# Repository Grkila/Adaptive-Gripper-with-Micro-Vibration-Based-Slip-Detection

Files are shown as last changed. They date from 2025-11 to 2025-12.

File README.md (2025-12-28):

# Adaptive Gripper with Micro-Vibration Based Slip Detection

A complete mechatronics project featuring a parallel gripper with real-time slip detection using a 3D magnetic sensor (TLV493D) and FFT-based signal analysis. The system autonomously adjusts grip force by detecting incipient slip through micro-vibration analysis, preventing object loss while minimizing applied force.

**Author:** Dušan Grković  
**Mentor:** Prof. Dr. Zoran Jeličić  
**Institution:** Faculty of Technical Sciences, Novi Sad  
**Date:** 2025

> All components of this project (PCB layout, firmware, and desktop application) were developed by the author. The mechanical design is based on [1] with significant modifications for sensor integration.

<p align="center">
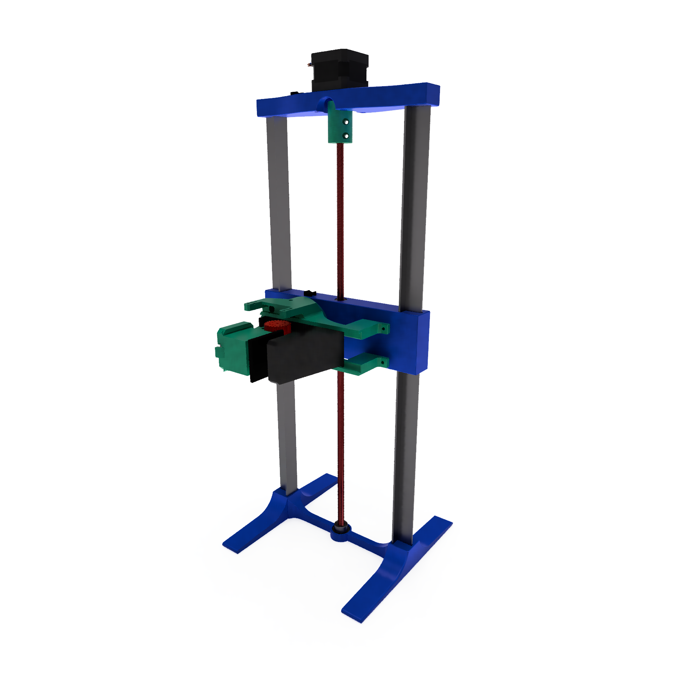
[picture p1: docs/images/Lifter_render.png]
  
</p>

<!-- ADD THIS BLOCK HERE -->
<p align="center">
  <a href="https://www.youtube.com/watch?v=gOe6JvAW2Xo">
    
  </a>
</p>
<!-- END BLOCK -->

## Table of Contents

1. [Overview](#overview)
2. [System Architecture](#system-architecture)
3. [Hardware](#hardware)
   - [Mechanical Design](#mechanical-design)
   - [Sensor Element](#sensor-element)
   - [Automated Test Platform](#automated-test-platform)
   - [Electronics](#electronics)
4. [Firmware](#firmware)
   - [Architecture](#firmware-architecture)
   - [Signal Processing](#signal-processing)
   - [State Machine](#state-machine)
5. [Communication Protocol](#communication-protocol)
6. [Desktop Application](#desktop-application)
7. [Test Results](#test-results)
8. [Hardware Files](#hardware-files)
9. [Repository Structure](#repository-structure)
10. [Build Instructions](#build-instructions)
11. [References](#references)

## Overview

This project presents a novel approach to adaptive grip force control where the conventional strain gauge based system is replaced with a contactless 3D magnetic sensor. The system detects the onset of slippage (incipient slip) by analyzing micro-vibrations generated during the stick-slip phenomenon.

### Key Features

- Real-time slip detection using FFT spectral analysis (40 Hz to 120 Hz band)
- Contactless measurement using TLV493D 3D Hall effect sensor
- Custom elastic sensor element with optimized natural frequency (~180 Hz)
- Dual-core FreeRTOS implementation on ESP32 (2 kHz sampling rate)
- Automated test platform with sensorless homing using TMC2209
- Desktop application for signal visualization and parameter tuning

### Operating Principle

1. **Stick-Slip Effect:** When an object begins to slip, the contact surface undergoes cycles of sticking and releasing, generating characteristic high-frequency vibrations
2. **Mechanical Transduction:** A custom elastic mechanism (planar spiral flexure) converts surface micro-displacements into magnet movement
3. **Magnetic Sensing:** The TLV493D sensor measures the magnet position changes caused by vibrations
4. **Spectral Analysis:** Real-time FFT identifies the spectral signature of slippage
5. **Adaptive Control:** A finite state machine increases grip force proportionally to slip intensity

## System Architecture

<p align="center">
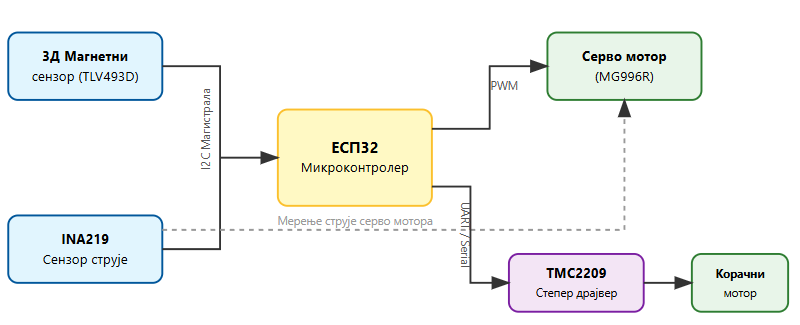
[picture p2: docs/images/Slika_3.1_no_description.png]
  
</p>

The system consists of three main subsystems:

| Subsystem | Components | Function |
|---|---|---|
| Sensing | TLV493D magnetic sensor, INA219 current sensor | Measure deformation and motor current |
| Control | ESP32 microcontroller, FreeRTOS | Real-time signal processing and decision making |
| Actuation | MG996R servo motor, NEMA17 stepper | Gripper actuation and test platform movement |

## Hardware

### Mechanical Design

The parallel gripper uses a rack and pinion mechanism for linear motion transformation. One finger is active (moving) while the other is passive (stationary) with the integrated sensor element.

**Note:** The mechanical design of the gripper is based on the open-source "Robot-manipulator" project by AnnaW21 [1], with significant modifications to integrate the custom sensor element and optimize it for the specific requirements of this project.

<p align="center">
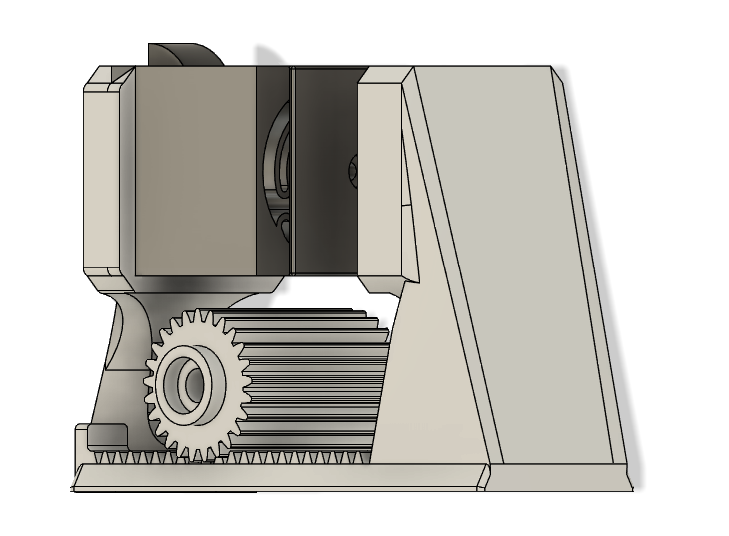
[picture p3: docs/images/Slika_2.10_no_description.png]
  
</p>

**Key specifications:**

- Material: PETG (FDM 3D printed)
- Actuator: MG996R servo motor (11 kg·cm torque at 6V)
- Drive: Rack and pinion with metal gears
- Contact surface: TPU insert for increased friction coefficient

CAD files are available in the `hardware/gripper/` directory as STEP format.

### Sensor Element

The elastic sensor element is the core innovation of this project. It uses a planar spiral flexure geometry that acts as a 3-DOF spring with the magnet mounted at the center.

<p align="center">
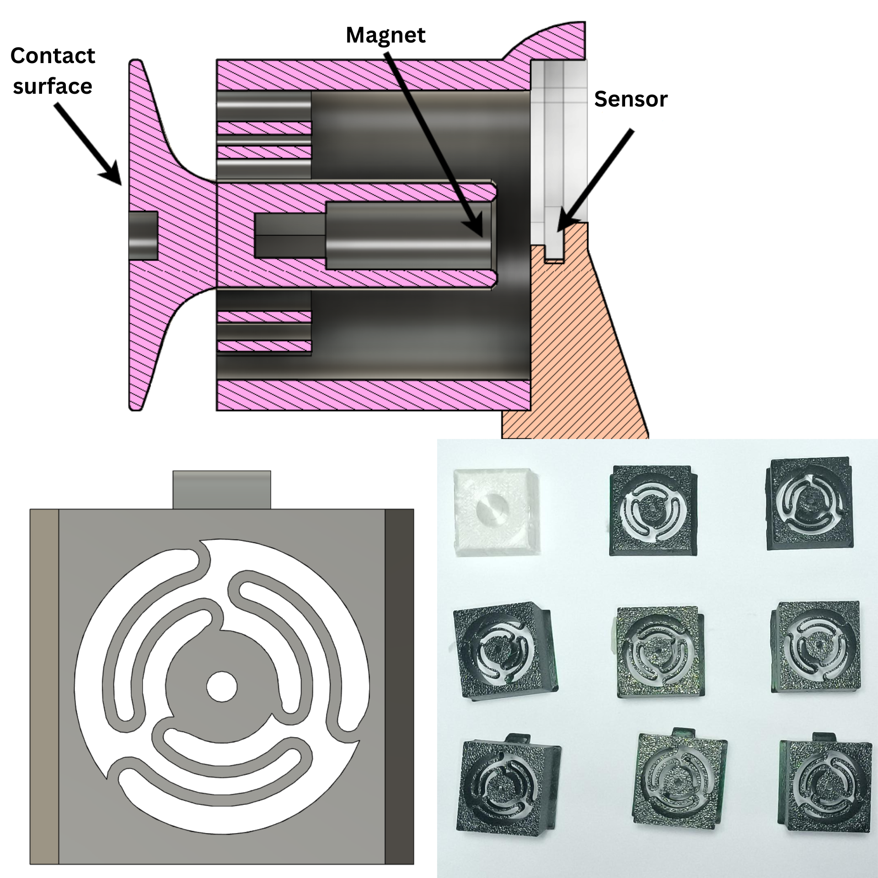
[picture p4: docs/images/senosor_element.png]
  
</p>

**Design parameters:**

- Geometry: 3-arm symmetric planar spiral flexure
- Natural frequency: ~180 Hz (tuned above slip detection band)
- Air gap: 4 mm between magnet and sensor
- Lever amplification: Geometry amplifies small displacements at contact surface

The natural frequency was empirically tuned through 10+ iterations using impulse response testing.

### Automated Test Platform

To ensure repeatable experimental conditions and eliminate operator subjectivity, a dedicated vertical positioning system was designed and built.

<p align="center">
  
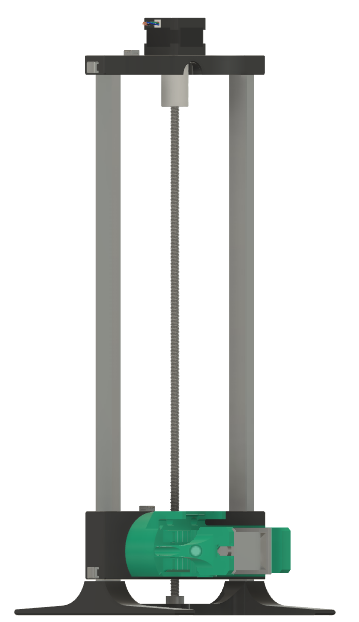
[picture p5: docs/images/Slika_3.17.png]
  
</p>

**Purpose:** Manual lifting introduces inconsistent accelerations and mechanical vibrations that can mask the slip signal or cause false detections. This platform guarantees identical velocity profiles across all test cycles. The use of this platform eliminates human variability in lifting speed and stability, which is essential for validating the sensitivity of the slip detection algorithm.

**Construction:**

- Frame: Aluminum T extrusion 
- Drive: M8x1.25mm lead screw coupled to NEMA17 stepper motor
- Controller: TMC2209 driver with StallGuard4 for sensorless homing
- Resolution: 2560 steps/mm (16 microsteps, 1.8 degree motor)

**Sensorless Homing Algorithm:**

Instead of physical limit switches, the system uses the TMC2209's StallGuard feature to detect when the platform reaches the mechanical stop:

1. Reduce motor current to 500mA (prevents damage on collision)
2. Move upward briefly (ensures room for acceleration)
3. Move downward while polling SG_RESULT via UART
4. When load increases (SG_RESULT drops below threshold for 3 consecutive reads), stop and set position to zero
5. Restore nominal current and acceleration parameters

> **Note:** The videos below are sped up for demonstration purposes.

<p align="center">
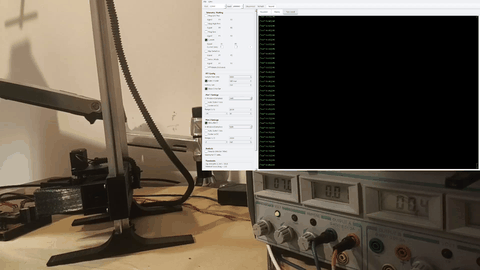
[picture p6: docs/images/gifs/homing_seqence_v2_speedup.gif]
  
  <br>
  <a href="docs/powerpoint/Video/homing_seqence_v2_speedup.mp4">▶️ Watch original video</a>
</p>

CAD files available in: `hardware/lifting platform/lifter.step`

### Electronics

<p align="center">
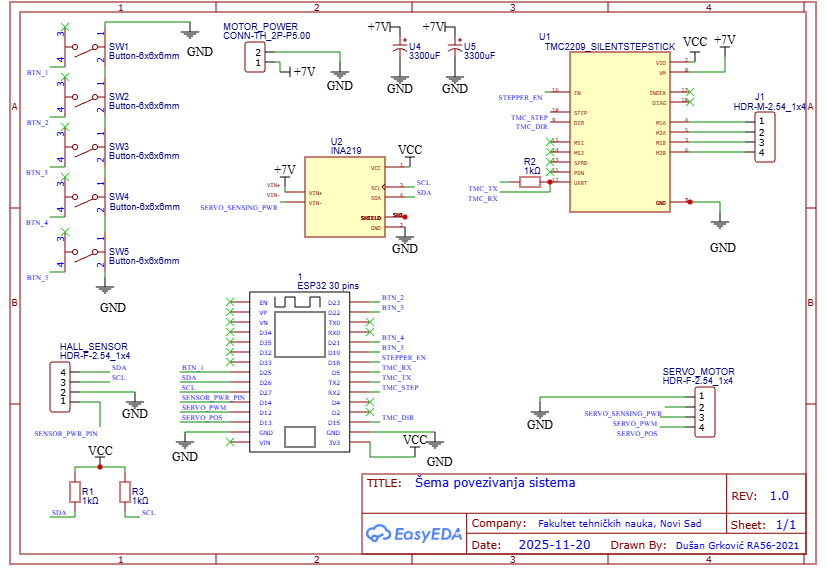
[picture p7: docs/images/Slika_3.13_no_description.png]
  
</p>

The electronic system is built around an ESP32 development module with the following interfaces:

| Component | Interface | Function |
|---|---|---|
| TLV493D | I2C (1 MHz) | 3D magnetic field measurement |
| INA219 | I2C | Servo motor current sensing |
| MG996R | PWM (50 Hz) | Gripper actuation |
| TMC2209 | UART + Step/Dir | Stepper motor control with StallGuard |
| Buttons (x5) | GPIO | Manual control interface |

**Button Functions:**

Five tactile buttons (active low with internal pull-up resistors) provide manual control:

| Button | Function |
|---|---|
| SW1 | Start adaptive gripping (grasp with optimal force) |
| SW2 | Full gripper open |
| SW3 | Raise platform to predefined height |
| SW4 | Lower platform to home position |
| SW5 | Emergency stop (halt platform at current position) |

**Power supply:** Single 7V input with bulk capacitors (2x 3300μF) for motor transient filtering.

Complete schematic available at: `hardware/pcb/Schematic_Gripper_diplomski.pdf`

PCB design files (EasyEDA format) available in: `hardware/pcb/EasyEda/`

## Firmware

### Firmware Architecture

The firmware implements a deterministic control loop using FreeRTOS on ESP32's dual-core architecture.

<p align="center">
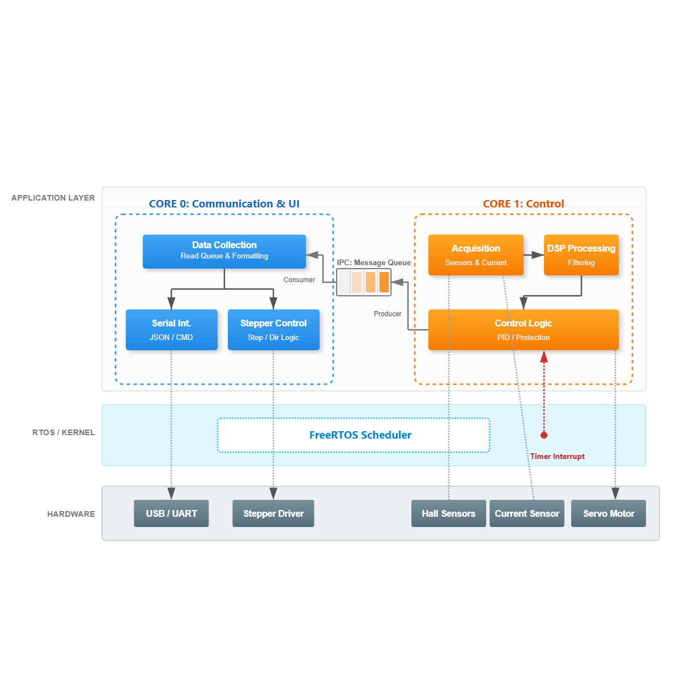
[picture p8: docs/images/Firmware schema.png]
  
</p>

**Core assignment:**

- **Core 0:** Communication task (telemetry, debug interface)
- **Core 1:** Real-time control loop (sensor acquisition, DSP, state machine)

Inter-core data sharing is protected by mutex to prevent race conditions.

### Scan Cycle

The main loop follows a PLC-style scan cycle triggered by hardware timer at 2 kHz:

1. **Read Inputs:** Magnetic sensor (2 kHz), current sensor (100 Hz), buttons (20 Hz)
2. **Process Logic:** Digital filtering, FFT computation, slip detection, FSM update
3. **Write Outputs:** Servo PWM update if position changed

### Signal Processing

<p align="center">
  
</p>

The signal processing pipeline:

1. **Calibration:** Offset removal based on startup readings
2. **Low-pass Filter (500 Hz):** Sensor noise elimination
3. **Band-split Filter (30 Hz):** Separates DC (grip force) from AC (vibrations)
4. **High-pass Filter:** AC component extraction by subtraction
5. **FFT Analysis:** 128-sample window, spectral power computation

**Slip indicator calculation:**

```
slip_indicator = frequency_weighted_power(40 Hz to 120 Hz band)
```

The frequency weighting gives higher importance to higher frequency components characteristic of slip events.

### State Machine

<p align="center">
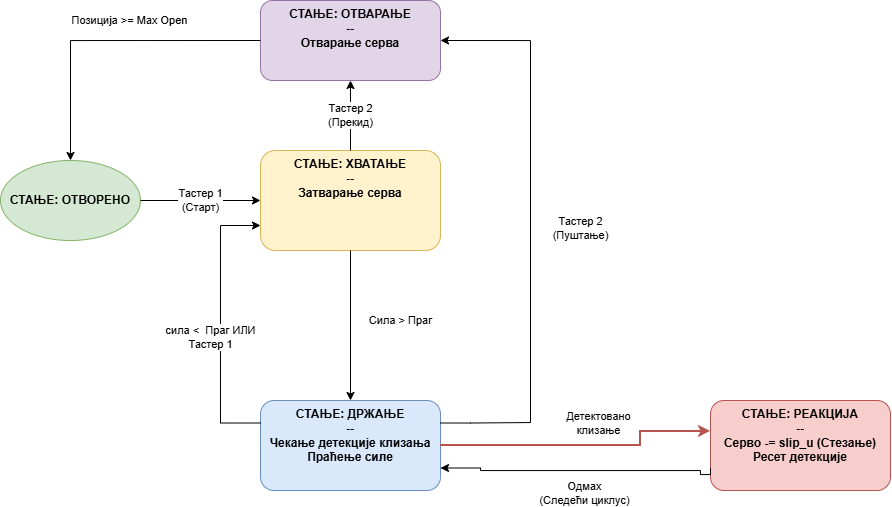
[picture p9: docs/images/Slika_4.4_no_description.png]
  
</p>

The gripper control FSM has five states:

| State | Entry Condition | Behavior |
|---|---|---|
| OPEN | Default / Button 2 | Gripper fully open |
| OPENING | Release command | Gradual opening |
| GRASPING | Button 1 | Close until contact detected (magnitude > threshold) |
| HOLDING | Contact established | Monitor for slip, maintain position |
| REACTING | Slip detected | Increase grip force proportionally |

## Communication Protocol

The firmware implements a bidirectional JSON-based protocol over serial (2000000 baud) for telemetry and configuration.

### Telemetry Output

Standard telemetry packet (fields depend on enabled streams):

```json
{"mlx":0.30,"mly":-0.46,"mlz":-0.28,"mag":0.71,"slip":0,"s_ind":1.76}
```

Each packet ends with a pipe character and XOR checksum for validation: `|5A`

### Configuration Commands

Send JSON commands to toggle specific data streams:

| Command | Description |
|---|---|
| `{"fft": true/false}` | Exclusive FFT streaming mode (pauses other metrics) |
| `{"mag_lowpass": true/false}` | Low-pass filtered magnetic data (mlx, mly, mlz, mag) |
| `{"mag_highpass": true/false}` | High-pass filtered magnetic data (mhx, mhy, mhz) |
| `{"mag_raw": true/false}` | Raw magnetic sensor data (rmx, rmy, rmz) |
| `{"current": true/false}` | Current sensor reading (cur) |
| `{"slip": true/false}` | Slip detection status and indicator (slip, s_ind) |
| `{"servo": true/false}` | Servo position and grip mode (srv, grp) |
| `{"system": true/false}` | System timing diagnostics (t) |

### FFT Data Format

When FFT mode is enabled, spectral data is streamed as:

```json
{"type":"fft","data":[10.5, 2.3, 0.1, ...]}
```

The data array contains 64 magnitude values from the high-pass filtered signal.

Full protocol documentation: `firmware/Thesis_Gripper/debugCommands.md`

## Desktop Application

A Python-based desktop application was developed for real-time signal visualization and system tuning.

### Features

- Activation/deactivation of telemetry streams (reduces serial bus load)
- Serial port and baud rate selection
- Configurable Y-axis range with auto-scaling option
- Configurable X-axis window (samples)
- Automatic DC centering
- Data recording to file
- Playback of recorded data with adjustable speed
- XOR checksum validation
- Multiple plots in single window
- Signal appearance customization (color, thickness, line type)
- Export to standard formats (CSV, PNG, matplotlib, SVG)
- Threshold indicators for parameter tuning
- Real-time FFT view with spectrogram history

### Screenshots

**Real-time signal visualization:**

<p align="center">
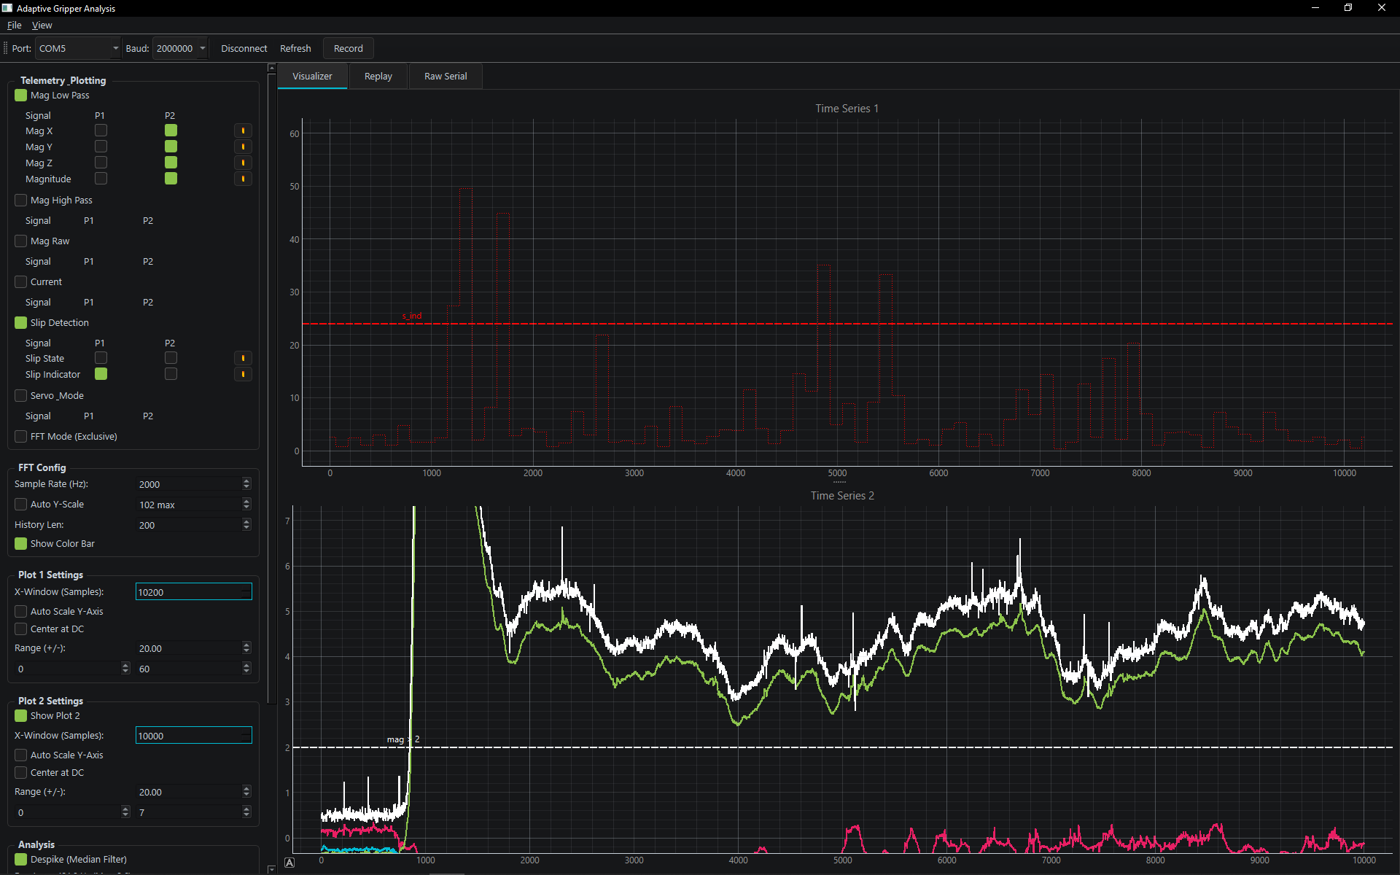
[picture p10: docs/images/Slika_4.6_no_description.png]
  
</p>

**Raw serial terminal:**

<p align="center">
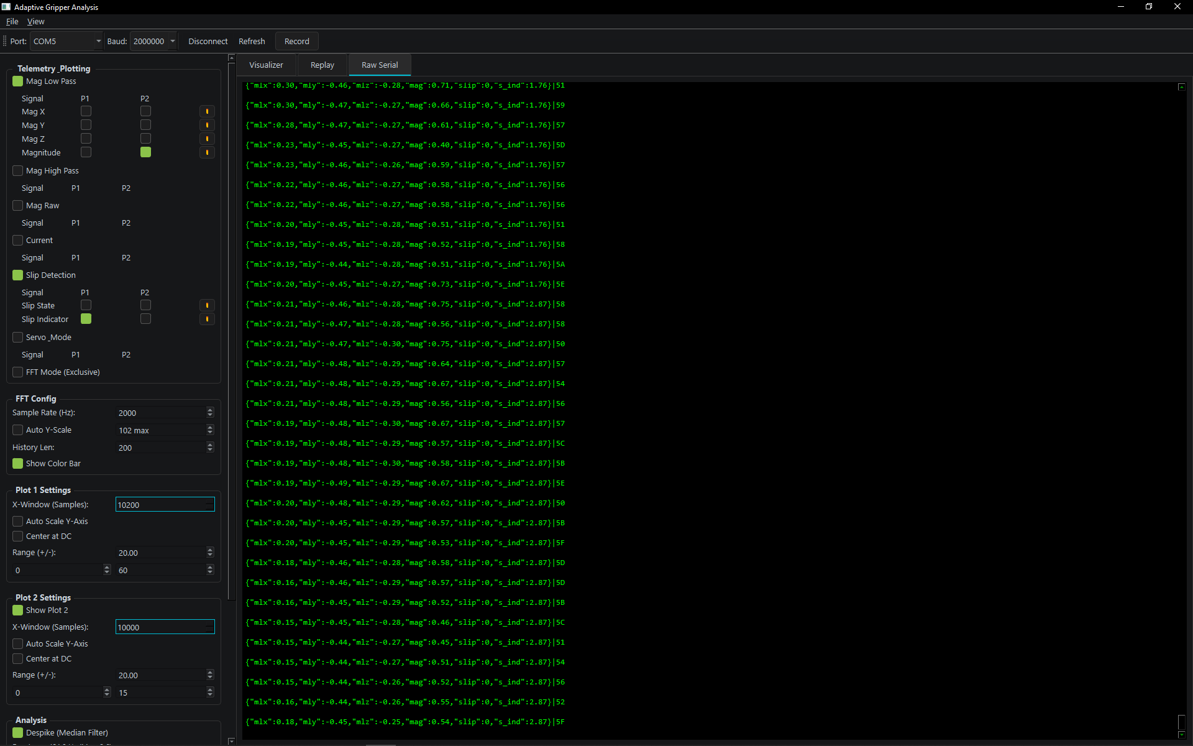
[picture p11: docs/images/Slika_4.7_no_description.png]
  
</p>

**Recorded data replay:**

<p align="center">
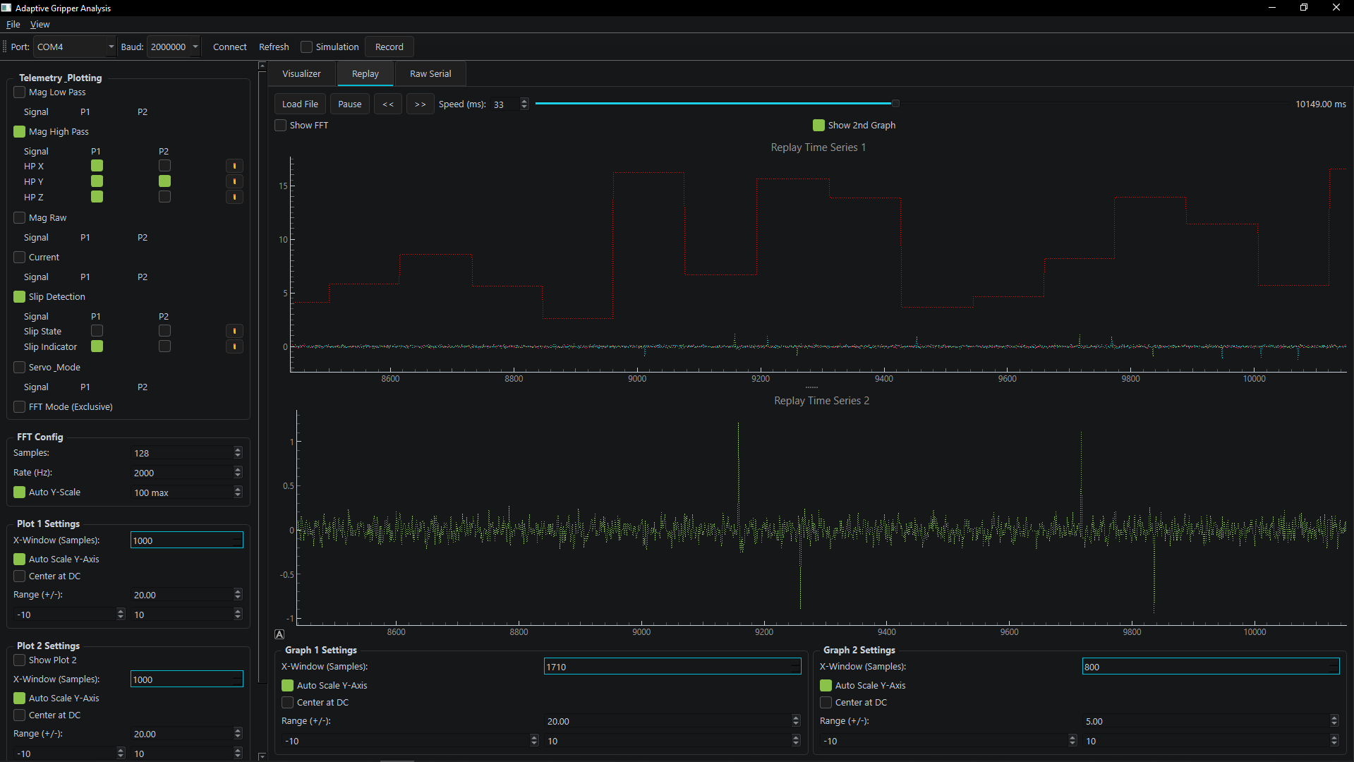
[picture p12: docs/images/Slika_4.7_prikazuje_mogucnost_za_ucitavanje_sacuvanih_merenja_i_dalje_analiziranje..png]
  
</p>

**FFT analysis with spectrogram:**

<p align="center">
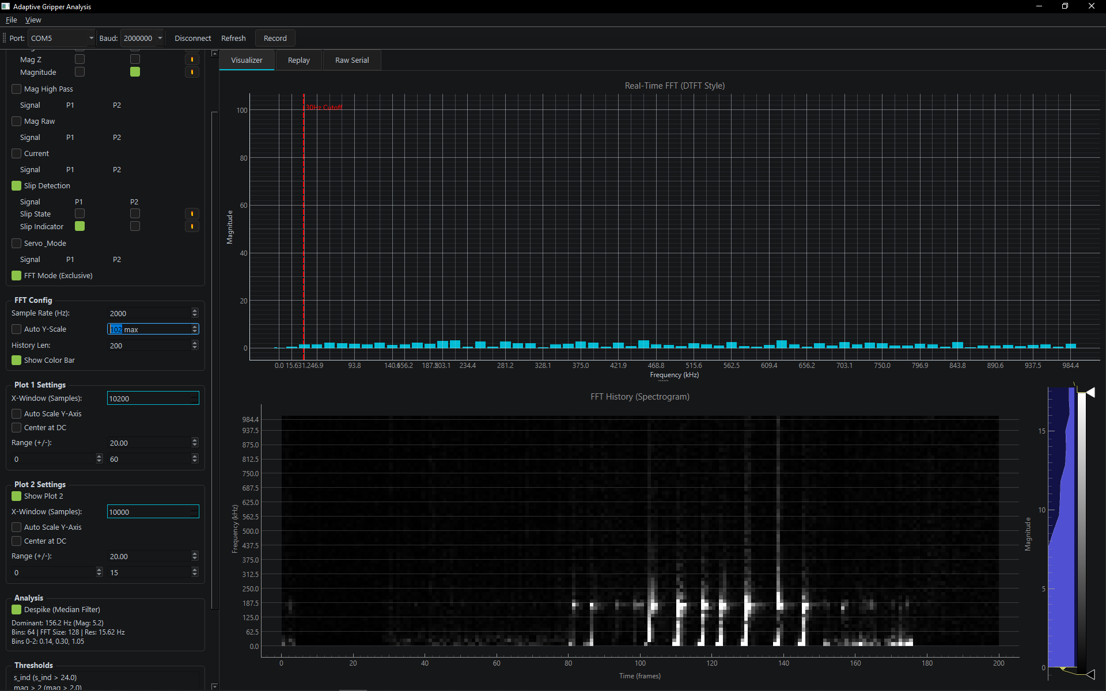
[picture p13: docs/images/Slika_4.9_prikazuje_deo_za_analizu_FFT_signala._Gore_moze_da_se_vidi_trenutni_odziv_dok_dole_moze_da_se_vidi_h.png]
  
</p>

## Test Results

The system was validated on various objects to demonstrate robustness and adaptability.

### Soft Objects (Sponge)

The gripper successfully grasped and held a deformable sponge with minimal compression (~5%), demonstrating the algorithm's ability to apply just enough force.

<p align="center">
  
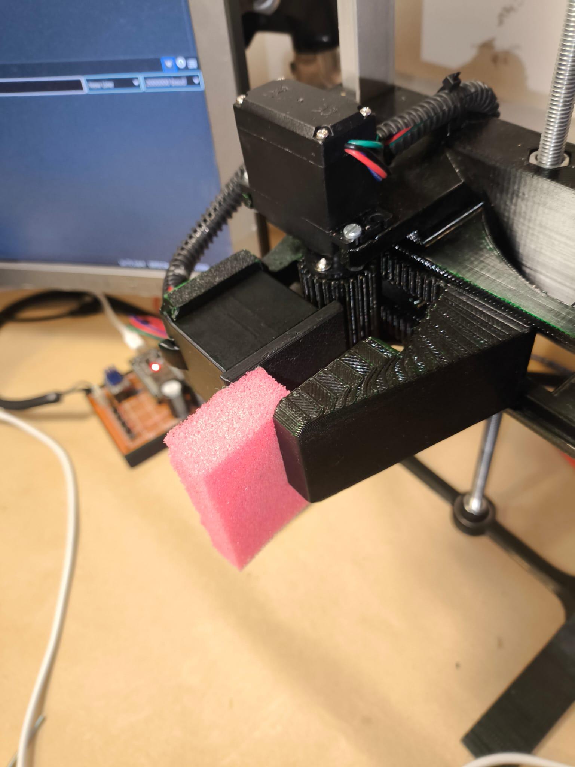
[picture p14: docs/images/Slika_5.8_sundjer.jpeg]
  
</p>

<p align="center">
  
  <br>
  <a href="docs/powerpoint/Video/sponge_speedup.mp4">▶️ Watch original video</a>
</p>

### Soft Objects (Cardboard Box)

A thin cardboard box (155g) was held without visible wall deformation, confirming optimal force application.

<p align="center">
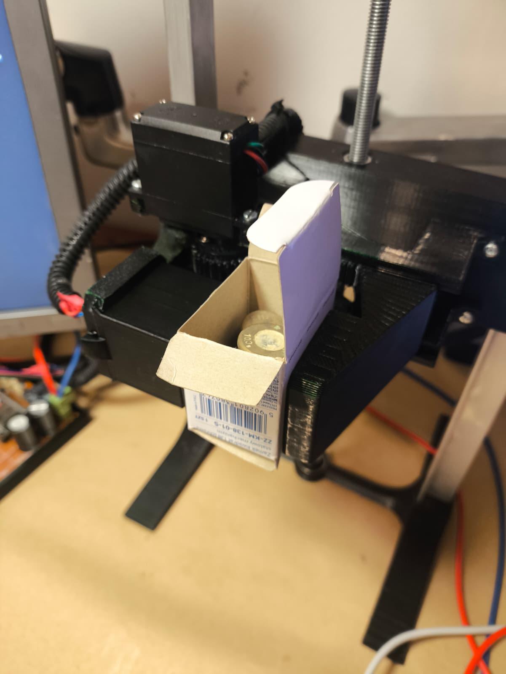
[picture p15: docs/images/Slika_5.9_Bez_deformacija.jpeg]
  
</p>

### Soft Objects (Cardboard Box)
A thin rigid PETG box (20g) was held without slippage, later it was added weights up to 500g confirming optimal force application.
Minimal slip ~5mm.

<p align="center">
  
  <br>
  <a href="docs/powerpoint/Video/testbox_speedup.mp4">▶️ Watch original video</a>
</p>

### Irregular Geometry (Cylindrical Object)

A 220g cylindrical tool was successfully held despite line contact instead of surface contact. Initial slip of ~10mm occurred during lifting transition before the system stabilized.

<p align="center">
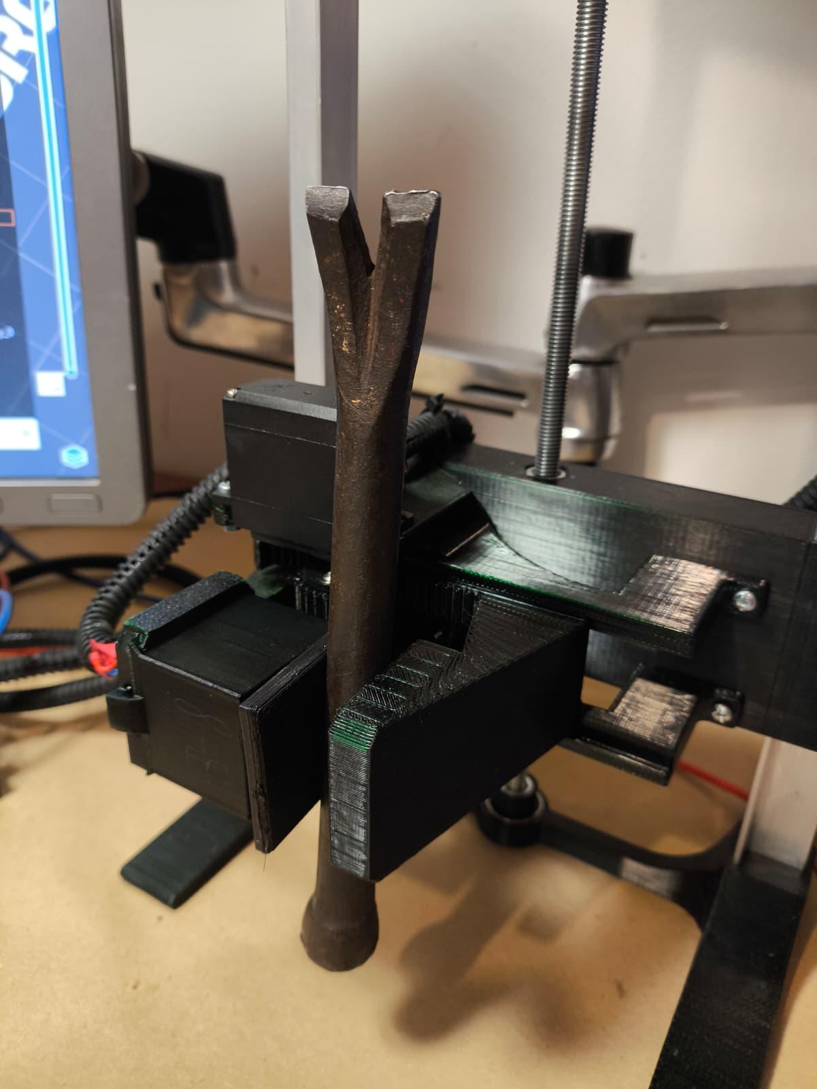
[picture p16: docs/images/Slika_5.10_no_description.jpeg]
  
</p>

<p align="center">
  
  <br>
  <a href="docs/powerpoint/Video/cylinder_speedup.mp4">▶️ Watch original video</a>
</p>

### Fragile Objects (Balloon)

The system also demonstrates capability with fragile objects like air-filled and water-filled balloons, adjusting grip force to prevent bursting while maintaining a secure hold.

<p align="center">
  
  
  <br>
  <a href="docs/powerpoint/Video/ballone_speedup.mp4">▶️ Watch air balloon video</a> | 
  <a href="docs/powerpoint/Video/waterballone_speedup.mp4">▶️ Watch water balloon video</a>
</p>

### Performance Metrics

| Parameter | Value |
|---|---|
| Sampling frequency | 2000 Hz |
| FFT window | 128 samples (64 ms) |
| Minimum reaction time | ~90 ms (buffer fill + processing + motor response) |
| Slip detection band | 40 Hz to 120 Hz |
| Slip threshold | 30 (weighted spectral power) |
| Contact detection threshold | 2.0 mT (magnitude change) |

## Hardware Files

All mechanical and electronic design files are provided for replication:

### Mechanical (STEP format)

| File | Description |
|---|---|
| `hardware/gripper/gripper.step` | Complete gripper assembly including rack and pinion mechanism, sensor housing, and finger geometry |
| `hardware/lifting platform/lifter.step` | Vertical test platform with linear guides and lead screw mount |

### Electronics

| File | Description |
|---|---|
| `hardware/pcb/Schematic_Gripper_diplomski.pdf` | Full circuit schematic (printable) |
| `hardware/pcb/EasyEda/1-Schematic_Gripper_diplomski.json` | EasyEDA schematic source file |
| `hardware/pcb/EasyEda/1-PCB_PCB_Gripper_diplomski.json` | EasyEDA PCB layout source file |

The PCB was designed but not manufactured; the prototype uses perfboard construction.

## Repository Structure

```
Adaptive-Gripper-with-Micro-Vibration-Based-Slip-Detection/
├── firmware/
│   └── Thesis_Gripper/
│       ├── Thesis_Gripper.ino    # Main program
│       ├── debugCommands.md               # Serial protocol documentation
│       └── src/
│           ├── Config.h                    # System configuration
│           ├── Types.h                     # Data structures
│           ├── Globals.h/.cpp              # Shared variables
│           ├── Drivers/                    # Hardware abstraction
│           │   ├── MagneticSensor.*        # TLV493D driver
│           │   ├── CurrentSensor.*         # INA219 driver
│           │   ├── ServoDriver.*           # PWM servo control
│           │   ├── MotorDriver.*           # TMC2209 stepper control
│           │   └── Buttons.*               # Button input handling
│           └── Logic/                      # Algorithms
│               ├── Filters.*               # Digital filters
│               ├── FFTProcessor.*          # FFT computation
│               ├── SlipDetection.*         # Slip detection algorithm
│               ├── GrippingFSM.*           # State machine
│               └── DebugTask.*             # Telemetry system
├── hardware/
│   ├── gripper/
│   │   └── gripper.step                    # Gripper CAD model
│   ├── lifting platform/
│   │   └── lifter.step                     # Test platform CAD model
│   └── pcb/
│       ├── Schematic_Gripper_diplomski.pdf # Circuit schematic
│       └── EasyEda/                        # PCB design files
├── software/
│   ├── signal_analysis_gui.py              # Desktop application
│   └── requirements.txt                    # Python dependencies
├── docs/
│   ├── images/                             # Documentation images
│   └── DIPLOMSKI.pdf                # Full thesis document
└── data/                                   # Sample measurement data
```

## Build Instructions

### Firmware

**Requirements:**

- Arduino IDE 2.x or PlatformIO
- ESP32 board support package
- Libraries: Wire, WiFi, arduinoFFT, TMCStepper, FastAccelStepper

**Steps:**

1. Open `firmware/Thesis_Gripper/Thesis_Gripper.ino` in Arduino IDE
2. Select board: ESP32 Dev Module
3. Configure upload speed: 921600
4. Adjust pin definitions in `Config.h` if needed
5. Upload to ESP32

### Desktop Application

**Requirements:**

- Python 3.8+
- Dependencies listed in `software/requirements.txt`

**Steps:**

```bash
cd software
pip install -r requirements.txt
python signal_analysis_gui.py
```

### Hardware

**3D Printing:**

- Material: PETG recommended (PLA may deform under friction heat)
- Layer height: 0.2 mm
- Infill: 20% for structural parts, gyroid infill
- Nozzle : 0.4 mm for sensor, 0.6 mm for rest of assembly 
- Wall loops 4 for sensor, 2 for rest of assembly
- Print orientation: Follow original STEP file orientation for optimal strength

**Electronics:**

- Prototype built on perfboard (PCB files provided but not manufactured)
- I2C pull-up resistors: 1kΩ (high speed operation)
- TMC2209 connection: 1kΩ resistor in series with UART TX

## References

1. AnnaW21. "Robot-manipulator." GitHub, 2021. [Online]. Available: https://github.com/AnnaW21/Robot-manipulator. (Repository containing 3D models and code for a robotic manipulator, whose gripper mechanical design was adapted for this work).

Full thesis with detailed derivations: `docs/DIPLOMSKI.pdf`

Presentation slides: [Diplomski_prez.pptx](docs/powerpoint/Diplomski_prez.pptx) (Requires PowerPoint 2018 or newer)

## License

This project was developed as a diploma thesis. For licensing inquiries, contact the author.

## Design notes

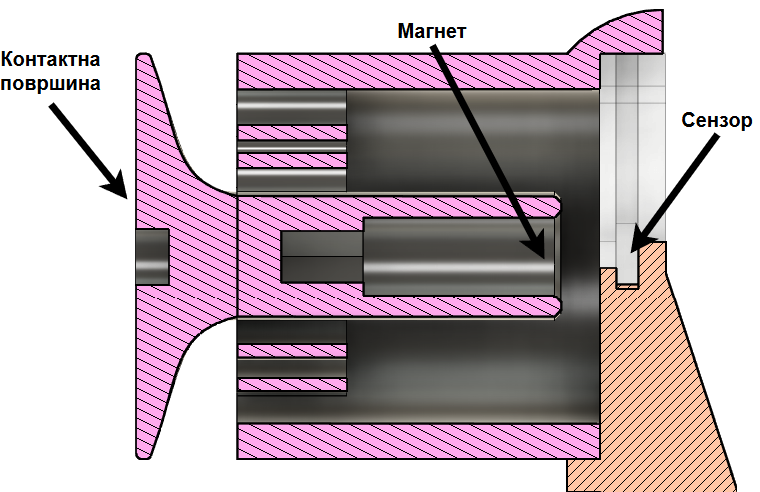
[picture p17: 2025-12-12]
docs/images/Slika_2.7_Primenom_ovog_resenja_je_osigurano_povecanje_amplituda,_ali_ovo_povecanje_dolazi_sa_cenom,_a_to_je_v.png

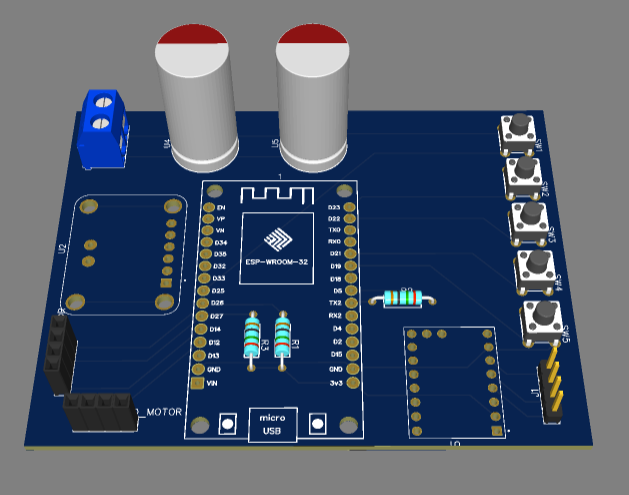
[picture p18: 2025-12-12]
docs/images/Slika_3.14_no_description.png

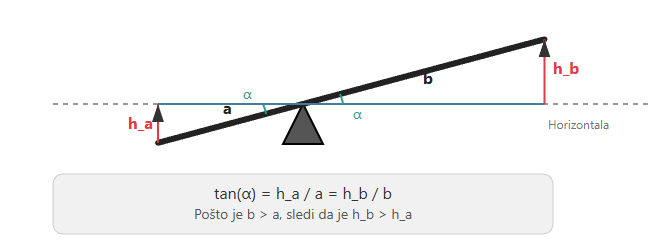
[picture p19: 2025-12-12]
docs/images/Slika_2.6_Za_levu_stranu_poluge,_visina_je_,_a_horizontalna_duzina_je_,_kao_sto_se_vidi_na_slici_2.6.png

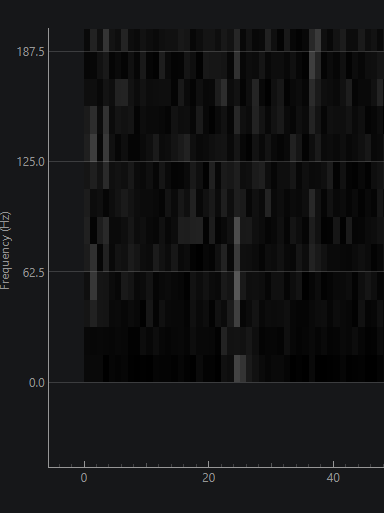
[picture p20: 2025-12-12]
docs/images/Slika_5.4_Kao_sto_se_vidi_na_slici_5.4_pre_klizanja_mozemo_da_uocimo_sum,_tokom_klizanja_se_vidi_visi_intentzi.png

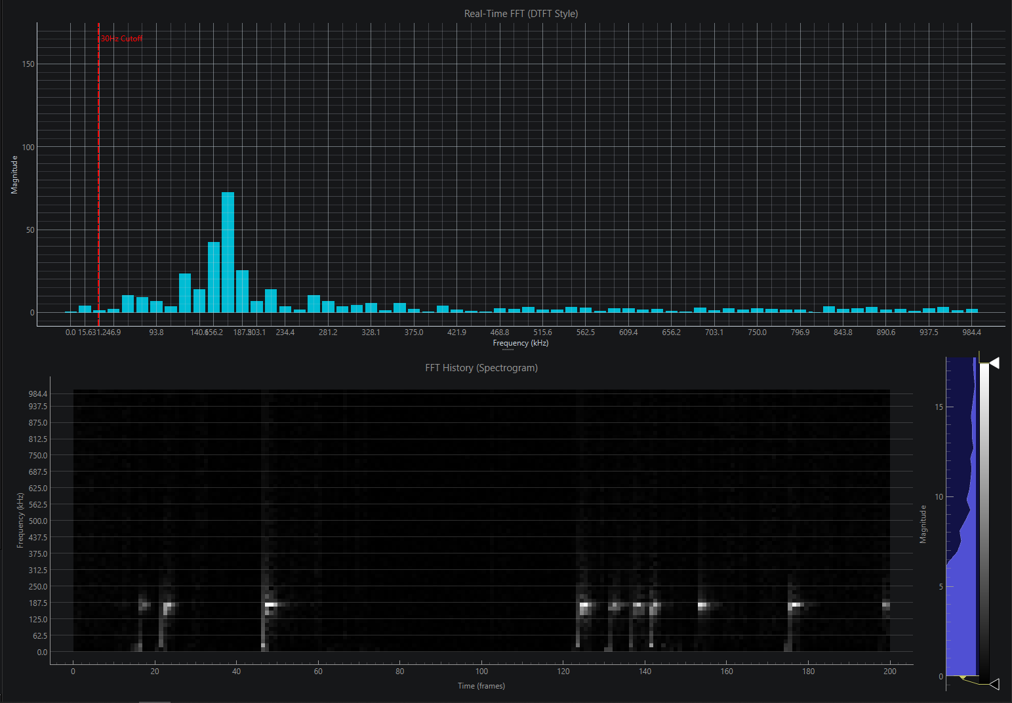
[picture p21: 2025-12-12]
docs/images/Slika_3.5_no_description.png

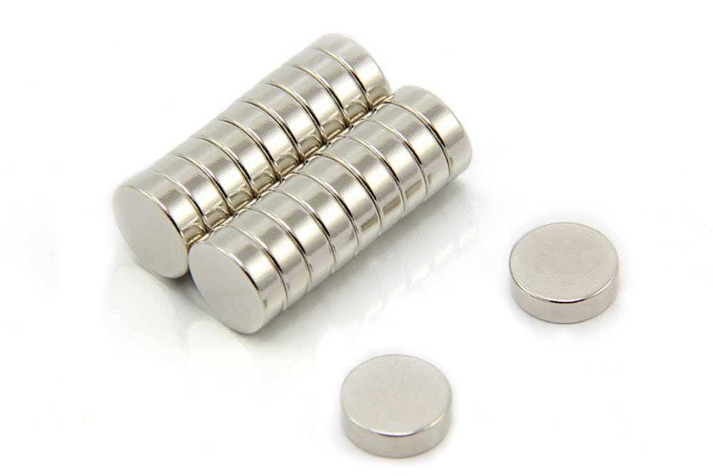
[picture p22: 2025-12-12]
docs/images/Slika_3.8_no_description.png

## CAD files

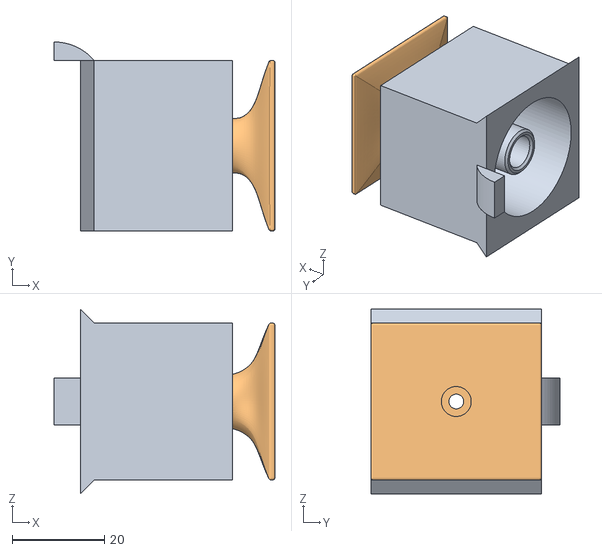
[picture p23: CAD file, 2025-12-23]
docs/powerpoint/3D model/coushon_compliant_v3_0.4mm nozzle.obj
47.9 x 41.0 x 40.0

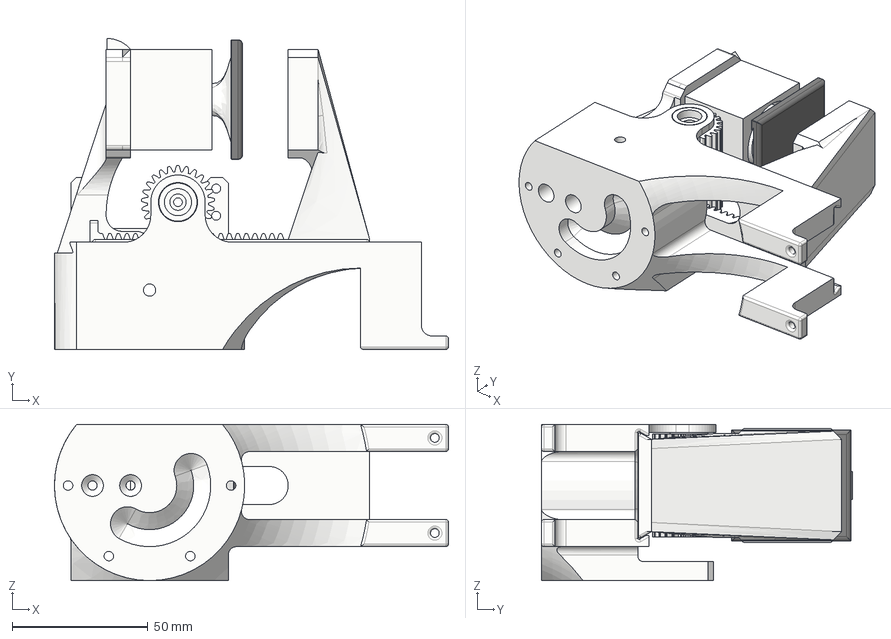
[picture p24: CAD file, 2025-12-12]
hardware/gripper/gripper.step
145.0 x 114.5 x 57.5 mm
губка_стационарная
sensor holder
coushon_compliant_v3_0.4mm nozzle
cushon cover

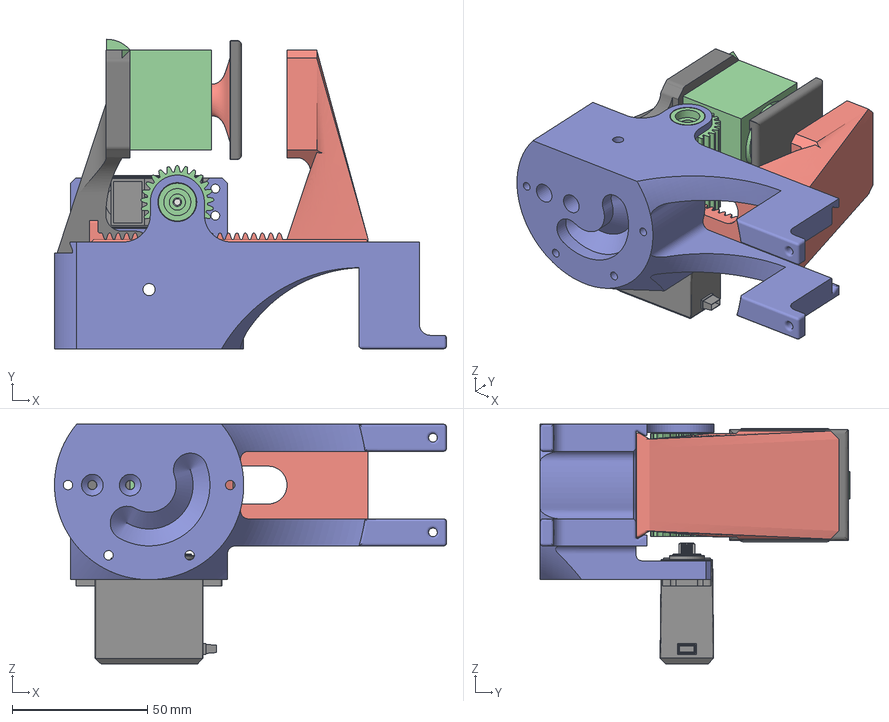
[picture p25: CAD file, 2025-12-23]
docs/powerpoint/3D model/gripper.3mf
145.0 x 114.5 x 88.6 mm

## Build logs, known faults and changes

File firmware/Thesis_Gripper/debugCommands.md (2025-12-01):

# Debug System Commands

**Baud Rate:** 921600  
**Format:** JSON  
**Terminator:** Newline (`\n`)

## Configuration Commands

Send these JSON strings to the Serial port to toggle specific data streams.

### FFT Mode (Exclusive)
*   `{"fft": true}` - Enables exclusive FFT streaming mode. (Pauses other metrics)
*   `{"fft": false}` - Disables FFT mode and returns to normal telemetry.

### Telemetry Toggles
*   `{"mag_lowpass": true}` / `false` - Low-Pass Filtered Magnetic Data (`mlx`, `mly`, `mlz`, `mag`). Alias: `mag_filtered`
*   `{"mag_highpass": true}` / `false` - High-Pass Filtered Magnetic Data (`mhx`, `mhy`, `mhz`)
*   `{"mag_raw": true}` / `false` - Raw Magnetic Data (`rmx`, `rmy`, `rmz`)
*   `{"current": true}` / `false` - Current Sensor (`cur`)
*   `{"slip": true}` / `false` - Slip Detection (`slip`, `s_ind`)
*   `{"servo": true}` / `false` - Servo & Mode (`srv`, `grp`)
*   `{"system": true}` / `false` - System Timing (`t`)

## Output Formats

### Normal Telemetry
Returns a JSON object with enabled fields:
```json
{"mx":12.3,"my":45.6,"mz":78.9,"mag":90.1,"cur":10.5,"slip":0,"t":500}
```

### FFT Data
Streamed when FFT mode is enabled:
```json
{"type":"fft","data":[10.5, 2.3, 0.1, ...]}
```
*   **data**: Array of magnitude values (High-Pass Filtered)

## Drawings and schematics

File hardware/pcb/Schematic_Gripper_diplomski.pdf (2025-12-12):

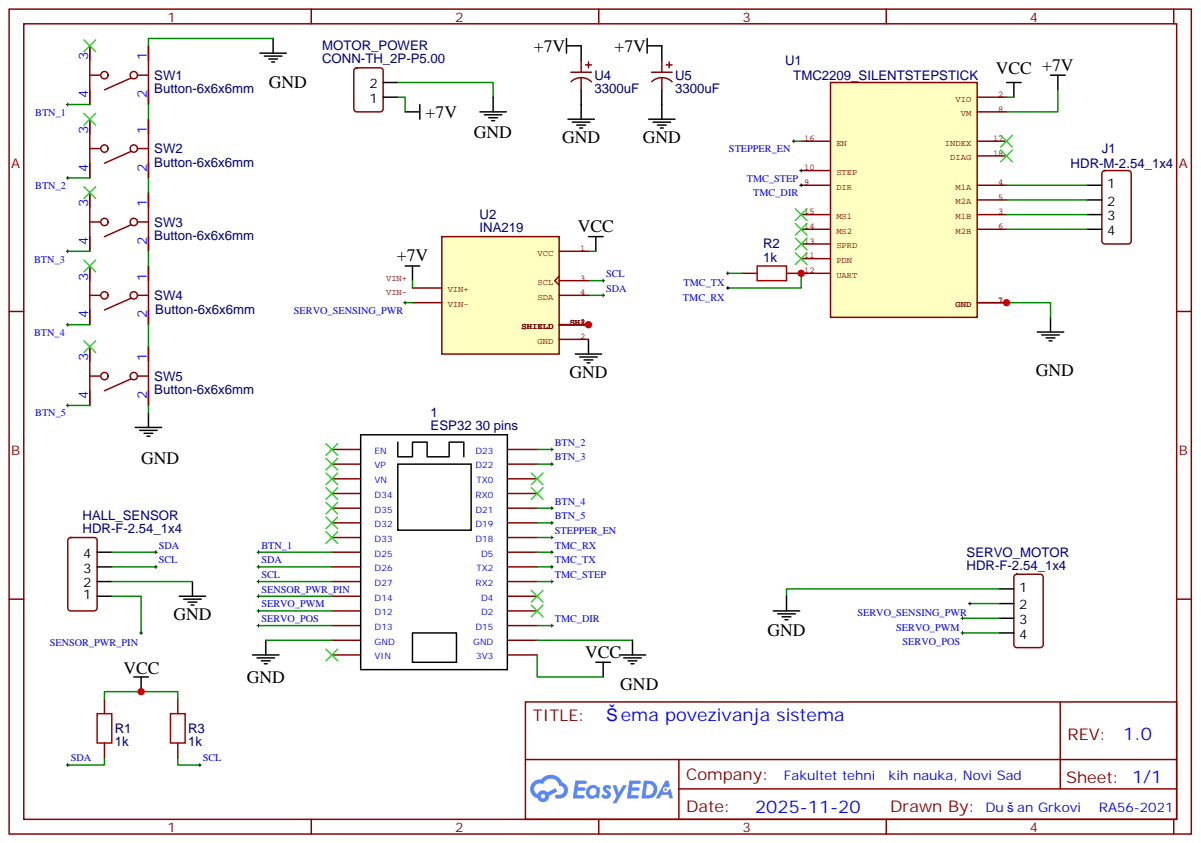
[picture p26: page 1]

Company: Fakultet tehni kih nauka, Novi Sad

Drawn By: Du an Grkovi RA56-2021

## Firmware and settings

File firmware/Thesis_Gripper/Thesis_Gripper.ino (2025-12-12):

/*
 * ADAPTIVE GRIPPING SYSTEM
 * Main control loop for the adaptive gripper project.
 */

#include <Wire.h>
#include <WiFi.h>

#include "src/Config.h"
#include "src/Types.h"
#include "src/Globals.h"
#include "src/Drivers/MagneticSensor.h"
#include "src/Drivers/CurrentSensor.h"
#include "src/Drivers/ServoDriver.h"
#include "src/Drivers/Buttons.h"
#include "src/Drivers/MotorDriver.h"
#include "src/Logic/Filters.h"
#include "src/Logic/FFTProcessor.h"
#include "src/Logic/SlipDetection.h"
#include "src/Logic/GrippingFSM.h"
#include "src/Logic/DebugTask.h"

unsigned long cycleCounter = 0;
// Sampling dividers (base frequency 2kHz)
const int CURRENT_READ_DIVIDER = 20;  // ~100Hz
const int BUTTON_READ_DIVIDER = 100;  // ~20Hz

// Timer interrupt for sampling synchronization
void ARDUINO_ISR_ATTR magneticSensor_ISR() {
  portENTER_CRITICAL_ISR(&timerMux);
  newDataAvailable = true;
  portEXIT_CRITICAL_ISR(&timerMux);
  xSemaphoreGiveFromISR(timerSemaphore, NULL);
}

void setup() {
  Serial.setTxBufferSize(4096);
  Serial.begin(2000000);
  
  WiFi.mode(WIFI_OFF);
  btStop();
  
  mutexI2C = xSemaphoreCreateMutex();
  if (mutexI2C == NULL) {
    Serial.println("Error: Failed to create I2C mutex");
    while(1) delay(1000);
  }
  
  Serial.println("\n--- ADAPTIVE GRIPPING SYSTEM ---");
  
  // Hardware initialization
  ServoDriver::init();
  if (!MagneticSensor::init()) {
    Serial.println("Error: Magnetic sensor init failed");
    while (1) delay(1000);
  }

  if (!CurrentSensor::init()) {
    Serial.println("Error: Current sensor init failed");
    while (1) delay(1000);
  }
  
  Buttons::init();
  MotorDriver::init();
  
  Serial.println("Homing Z-axis...");
  MotorDriver::runHomingRoutine();
  Serial.println("Homing complete.");
  
  Filters::init();
  MagneticSensor::calibrate(calData);
  
  // Configure timer for determinstic loop
  timerSemaphore = xSemaphoreCreateBinary();
  timer = timerBegin(1000000);
  timerAttachInterrupt(timer, &magneticSensor_ISR);
  timerAlarm(timer, SCAN_INTERVAL_US, true, 0); 

  DebugTask::init();
  
  Serial.flush();
  delay(500);
  Serial.println("System Ready.");
}

void readInputsSequentially() {
  // High priority: Magnetic sensor (2kHz)
  double raw_x=0, raw_y=0, raw_z=0;
  MagneticSensor::read(raw_x, raw_y, raw_z);
  MagneticSensor::applyCalibration(raw_x, raw_y, raw_z, calData);
  
  magData.x = raw_x;
  magData.y = raw_y;
  magData.z = raw_z;
  magData.magnitude = MagneticSensor::calculateMagnitude(raw_x, raw_y, raw_z);
  
  Filters::applyMainFilterMagneticSensor(magData);
  Filters::applyBandSplitFilterMagneticSensor(magData);

  // Low priority: Current sensing (sliced)
  if (cycleCounter % CURRENT_READ_DIVIDER == 0) {
      float raw_current = CurrentSensor::readCurrent_mA();
      current_mA = Filters::filterCurrent(raw_current);
  }

  // Low priority: UI Buttons
  if (cycleCounter % BUTTON_READ_DIVIDER == 0) {
      buttons = Buttons::read();
  }
}

void processLogic() {
  FFTProcessor::process(magData);
  SlipDetection::detect();
  GrippingFSM::process(buttons, current_mA, magData.magnitude);

  // Manual lift control
  static bool lastBtn3 = false, lastBtn4 = false, lastBtn5 = false;
  
  if (buttons.button_3 && !lastBtn3) {
      MotorDriver::moveToMM(150);
  }
  lastBtn3 = buttons.button_3;
 
  if (buttons.button_4 && !lastBtn4) {
      MotorDriver::moveToMM(0);
  }
  lastBtn4 = buttons.button_4;
  
  if (buttons.button_5 && !lastBtn5) {
      MotorDriver::setTargetSpeed(0);
  }
  lastBtn5 = buttons.button_5;
}

void writeOutputs() {
  ServoDriver::writePositionIfChanged(servo_position);
}

void loop() {
  // Wait for timer trigger to start cycle
  if (xSemaphoreTake(timerSemaphore, portMAX_DELAY) == pdTRUE) {
    readInputsSequentially();
    processLogic();
    writeOutputs();

    cycleCounter++;
    DebugTask::updateData();
  }
}

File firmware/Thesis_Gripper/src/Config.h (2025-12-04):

#ifndef CONFIG_H
#define CONFIG_H

#include <Arduino.h>

// ============================================
// PIN DEFINITIONS
// ============================================
constexpr int SERVO_PIN = 12;
constexpr int ANALOG_FEEDBACK_PIN = 13;
constexpr int MAGNETIC_SENSOR_POWER_PIN = 14;
constexpr int BUTTON_1_PIN = 25;
constexpr int BUTTON_2_PIN = 23;
constexpr int BUTTON_3_PIN = 22;
constexpr int BUTTON_4_PIN = 21;
constexpr int BUTTON_5_PIN = 19;
constexpr int SDA_PIN=26;
constexpr int SCL_PIN=27;

// ============================================
// SERVO CONFIGURATION
// ============================================
constexpr int SERVO_FULLY_OPEN = 180;
constexpr int SERVO_FULLY_CLOSED = 0;

// ============================================
// TIMING CONFIGURATION
// ============================================
constexpr unsigned long SCAN_INTERVAL_US = 500;  // 500us scan cycle (2kHz)
constexpr unsigned long CURRENT_READ_INTERVAL_MS = 10; // 10ms (100Hz)
constexpr unsigned long BUTTON_READ_INTERVAL_MS = 50;  // 50ms (20Hz) for button debounce/polling

// ============================================
// SAMPLING AND FFT CONFIGURATION
// ============================================
constexpr uint16_t FFT_SAMPLES = 128;  // Must be power of 2
constexpr double MAGNETIC_SENSOR_SAMPLING_FREQUENCY = 1000000.0 / (double)SCAN_INTERVAL_US;

// ============================================
// FILTER CONFIGURATION
// ============================================
#ifndef PI
#define PI 3.14159
#endif

// 30 Hz low-pass filter cutoff
constexpr double FILTER_30HZ_CUTOFF_FREQ = 30.0;

// 500 Hz low-pass filter cutoff (main filter)
constexpr double FILTER_500HZ_CUTOFF_FREQ = 500.0;

// Current filter (5 Hz at 100 Hz sampling)
constexpr double FILTER_CURRENT_CUTOFF_FREQ = 5.0;
constexpr double FILTER_CURRENT_SAMPLE_RATE = 100.0;


// ============================================
// SLIP DETECTION CONFIGURATION
// ============================================
constexpr float SLIP_THRESHOLD =30.0f;
constexpr uint16_t SLIP_FREQ_START_HZ = 60;
constexpr uint16_t SLIP_FREQ_END_HZ = 125;
constexpr int SLIP_DETECTION_IGNORE_CYCLES = 100; // Ignore slip for 50 cycles (25ms) after movement to filter vibration
constexpr float GRIP_SLIP_MARGIN_FALSE_POSITIVE=2.5f;
// ============================================
// GRIPPING STATE MACHINE TIMING
// ============================================
constexpr unsigned long REACTION_COOLDOWN_MS = 64;
constexpr unsigned long BACKOFF_DELAY_MS = 2000;
constexpr unsigned long BACKOFF_INTERVAL_MS = 1000;

// ============================================
// GRIPPING THRESHOLDS
// ============================================
constexpr float GRIP_CURRENT_THRESHOLD_MA = 0.0f;
constexpr float GRIP_MAGNITUDE_THRESHOLD = 2.0f;
constexpr float GRIP_MAGNITUDE_DROP_MARGIN = 0.2f;

// ============================================
// MOTOR SPEED SETTINGS
// ============================================
constexpr int GRASPING_STEP = 1;
constexpr int OPENING_STEP = 5;
constexpr int BACKOFF_STEP = 1;
constexpr int MAX_REACTION_STEPS = 4;
// ============================================
// DEBUG TASK CONFIGURATION
// ============================================
constexpr unsigned long DEBUG_PRINT_INTERVAL_MS = 1;
constexpr uint32_t DEBUG_TASK_STACK_SIZE = 8192;
constexpr UBaseType_t DEBUG_TASK_PRIORITY = 1;
constexpr BaseType_t DEBUG_TASK_CORE = 0;

// ============================================
// I2C CONFIGURATION
// ============================================
constexpr uint32_t MAGNETIC_I2C_CLOCK_SPEED = 1000000;  
// ============================================
// TMC2209 MOTOR CONFIGURATION
// ============================================
constexpr int TMC_RX_PIN = 5;    // TMC2209 PDN_UART
constexpr int TMC_TX_PIN = 17;    // Connect to RX via 1k Resistor
constexpr int TMC_EN_PIN = 18;    // Enable pin
constexpr int TMC_STEP_PIN = 16;
constexpr int TMC_DIR_PIN = 15;
constexpr float TMC_R_SENSE = 0.11f;
constexpr uint8_t TMC_DRIVER_ADDR = 0b00;
constexpr int TMC_STALL_VALUE = 3; // Stall Sensitivity (0-255)

constexpr int TMC_RUN_CURRENT = 1000; // mA
constexpr int TMC_MICROSTEPS = 16;     

// Speed Settings
constexpr int TMC_MAX_SPEED = 6000;      // Steps per second
constexpr int TMC_ACCELERATION = 5000;   // Steps per second^2

// Automatic Homing Configuration
constexpr int TMC_HOMING_CURRENT = 500;    // mA
constexpr int TMC_HOMING_SPEED = 5000;    // Steps per second
constexpr int TMC_HOMING_THRESHOLD = 3;   // StallGuard threshold for homing
constexpr int TMC_HOMING_CONSECUTIVE_STALLS = 3; // Number of consecutive stalls to confirm stall
constexpr int TMC_HOMING_DIRECTION = -1;    // 1 for forward/up, -1 for backward/down
constexpr int TMC_HOMING_TIMEOUT_MS = 1000000; // Safety timeout

constexpr float TMC_STEPS_PER_MM = 2560.0f; // https://blog.prusa3d.com/calculator_3416/#MotorStuffSPML 1.8deg motor m8 metric screw

#endif // CONFIG_H

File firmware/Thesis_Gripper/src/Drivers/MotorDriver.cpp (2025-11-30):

#include "MotorDriver.h"
#include <HardwareSerial.h>
#include <freertos/semphr.h>

// Static member initialization
volatile bool MotorDriver::enabled = false;
volatile bool MotorDriver::initialized = false;
TMC2209Stepper* MotorDriver::driver = nullptr;
FastAccelStepperEngine MotorDriver::engine = FastAccelStepperEngine();
FastAccelStepper* MotorDriver::stepper = nullptr;
SemaphoreHandle_t MotorDriver::driverMutex = NULL;

void MotorDriver::init() {
    Serial.println("[MTR] init() starting...");
    
    // 1. Create mutex FIRST before anything else
    Serial.println("[MTR] Creating mutex...");
    driverMutex = xSemaphoreCreateRecursiveMutex();
    if (driverMutex == NULL) {
        Serial.println("[MTR-FATAL] Failed to create mutex!");
        return;
    }

    // 2. Initialize Serial
    Serial.println("[MTR] Initializing Serial2...");
    Serial2.begin(115200, SERIAL_8N1, TMC_RX_PIN, TMC_TX_PIN);
    delay(100); 

    // 3. Setup Pins
    // FastAccelStepper handles pins, but we ensure EN is initially high (disabled)
    pinMode(TMC_EN_PIN, OUTPUT);
    digitalWrite(TMC_EN_PIN, HIGH);

    // 4. Create and Configure TMC2209 Driver (UART)
    Serial.println("[MTR] Creating TMC2209Stepper object...");
    driver = new TMC2209Stepper(&Serial2, TMC_R_SENSE, TMC_DRIVER_ADDR);
    if (driver == nullptr) {
        Serial.println("[MTR-FATAL] Failed to allocate driver!");
        return;
    }
    
    Serial.println("[MTR] Configuring driver...");
    driver->begin();
    driver->toff(5);
    driver->mstep_reg_select(true); // 1. Tell driver to IGNORE physical MS1/MS2 pins
    driver->microsteps(TMC_MICROSTEPS);
    driver->rms_current(TMC_RUN_CURRENT);
    driver->iholddelay(10);
    driver->en_spreadCycle(true); // StealthChop
    driver->pwm_autoscale(true);
    driver->TCOOLTHRS(0xFFFFF);
    driver->SGTHRS(TMC_STALL_VALUE);
    
    // IMPORTANT: Set VACTUAL to 0 to enable STEP/DIR control
    driver->VACTUAL(0);
    Serial.print("[MTR] Driver sees Microsteps: ");
    Serial.println(driver->microsteps()); 
    Serial.println("[MTR] Driver configuration complete (STEP/DIR mode)");

    // 5. FastAccelStepper Setup
    Serial.println("[MTR] Initializing FastAccelStepper...");
    engine.init();
    stepper = engine.stepperConnectToPin(TMC_STEP_PIN);
    
    if (stepper) {
        stepper->setDirectionPin(TMC_DIR_PIN);
        stepper->setEnablePin(TMC_EN_PIN);
        stepper->setAutoEnable(true); // Automatically manage EN pin
        
        // Configuration from Config.h
        stepper->setAcceleration(TMC_ACCELERATION); 
        stepper->setSpeedInHz(TMC_MAX_SPEED);
        
        Serial.println("[MTR] FastAccelStepper initialized");
    } else {
        Serial.println("[MTR-FATAL] Failed to create stepper!");
    }

    initialized = true;
    Serial.println("[MTR] init() complete");
}

void MotorDriver::moveTo(long absolutePosition) {
    if (stepper) stepper->moveTo(absolutePosition);
}

void MotorDriver::moveRelative(long relativePosition) {
    if (stepper) stepper->move(relativePosition);
}

long MotorDriver::getPosition() {
    if (stepper) return stepper->getCurrentPosition();
    return 0;
}

long MotorDriver::getTargetPosition() {
    if (stepper) return stepper->targetPos();
    return 0;
}

void MotorDriver::setTargetSpeed(int32_t speed) {
    if (!stepper) return;
    
    if (speed == 0) {
        stepper->stopMove();
        enabled = false;
    } else {
        // speed is in steps/s
        uint32_t speedAbs = abs(speed);
        if (speedAbs > TMC_MAX_SPEED) speedAbs = TMC_MAX_SPEED;
        if (speedAbs < 100) speedAbs = 100; // Minimum speed safety?
        
        stepper->setSpeedInHz(speedAbs);
        
        if (speed > 0) {
            stepper->runForward();
        } else {
            stepper->runBackward();
        }
        enabled = true;
    }
}

void MotorDriver::stop() {
    if (stepper) stepper->stopMove();
}

void MotorDriver::enable() {
    if (stepper) stepper->enableOutputs();
}

void MotorDriver::disable() {
    if (stepper) stepper->disableOutputs();
}

int32_t MotorDriver::getLoad() {
    if (!initialized || !driver) return 0;
    
    int32_t result = 0;
    if (xSemaphoreTakeRecursive(driverMutex, pdMS_TO_TICKS(10)) == pdTRUE) {
        result = driver->SG_RESULT();
        xSemaphoreGiveRecursive(driverMutex);
    }
    return result;
}

void MotorDriver::runHomingRoutine() {
    Serial.println("[MTR] Homing routine starting...");
    if (!initialized || !stepper) {
        Serial.println("[MTR] Not initialized, cannot home.");
        return;
    }

    // 1. Setup for homing
    if (xSemaphoreTakeRecursive(driverMutex, portMAX_DELAY) == pdTRUE) {
        driver->rms_current(TMC_HOMING_CURRENT); 
        driver->en_spreadCycle(false);
        driver->SGTHRS(TMC_HOMING_THRESHOLD);
        xSemaphoreGiveRecursive(driverMutex);
    }

    // 1.5 Move AWAY first
    Serial.println("[MTR] Moving AWAY from home...");
    
    stepper->setSpeedInHz(TMC_HOMING_SPEED);
    
    if (TMC_HOMING_DIRECTION > 0) {
        stepper->runBackward(); 
    } else {
        stepper->runForward();
    }
    
    delay(5000); // Run for 5 seconds
    stepper->forceStop(); 
    delay(1000);

    // 2. Move TOWARDS home and check Stall
    Serial.println("[MTR] Moving TOWARDS home...");
    if (TMC_HOMING_DIRECTION > 0) {
        stepper->runForward();
    } else {
        stepper->runBackward();
    }

    unsigned long startTime = millis();
    bool stalled = false;
    
    delay(2000); // Skip acceleration spike

    int consecutiveStalls = 0;

    while (millis() - startTime < TMC_HOMING_TIMEOUT_MS) {
        int32_t load = getLoad(); 
        if ((millis() % 200) == 0) Serial.printf("[MTR] Load: %d\n", load);

        if (load < TMC_HOMING_THRESHOLD) { 
             consecutiveStalls++;
             if (consecutiveStalls >= TMC_HOMING_CONSECUTIVE_STALLS) {
                 Serial.printf("[MTR] Stall detected! Load: %d < %d (Consecutive: %d)\n", load, TMC_HOMING_THRESHOLD, consecutiveStalls);
                 stalled = true;
                 break;
             }
        } else {
             consecutiveStalls = 0;
        }
        
        if (!stepper->isRunning()) break;
        
        delay(10);
    }

    // 3. Stop
    stepper->forceStop();
    
    if (!stalled) {
        Serial.println("[MTR] Homing timed out without stall.");
    }

    // 4. Reset Position and Config
    stepper->setCurrentPosition(0);
    
    if (xSemaphoreTakeRecursive(driverMutex, portMAX_DELAY) == pdTRUE) {
        stepper->setSpeedInHz(TMC_MAX_SPEED);
        stepper->setAcceleration(TMC_ACCELERATION);
        driver->rms_current(TMC_RUN_CURRENT);
        driver->SGTHRS(TMC_STALL_VALUE);
        xSemaphoreGiveRecursive(driverMutex);
    }
    
    Serial.println("[MTR] Homing routine complete.");
   
}

long MotorDriver::mmToSteps(float mm) {
    return (long)round(mm * TMC_STEPS_PER_MM);
}
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

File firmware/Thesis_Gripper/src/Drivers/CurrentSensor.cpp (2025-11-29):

#include "CurrentSensor.h"
#include "../Globals.h"
#include <Arduino.h>

namespace CurrentSensor {
  
  // Static sensor instance
  static Adafruit_INA219 ina219;
  
  bool init() {
    Serial.println("[INA219] Initializing...");
    
    bool success = false;
    if (mutexI2C != NULL && xSemaphoreTake(mutexI2C, pdMS_TO_TICKS(100)) == pdTRUE) {
        success = ina219.begin();
        xSemaphoreGive(mutexI2C);
    }
    
    if (!success) {
      Serial.println("[INA219] ✗ FAILED - Check wiring!");
      return false;
    }
    Serial.println("[INA219] ✓ Ready");
    return true;
  }
  
  float readCurrent_mA() {
    if (mutexI2C == NULL) return 0.0f;
    
    float result = 0.0f;
    if (xSemaphoreTake(mutexI2C, pdMS_TO_TICKS(5)) == pdTRUE) {
        result = ina219.getCurrent_mA();
        xSemaphoreGive(mutexI2C);
    }
    return result;
  }
  
  Adafruit_INA219& getSensor() {
    return ina219;
  }
}

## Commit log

2025-11-29 Add motor control functionality and improve mutex safety checks
    - Integrated MotorDriver for controlling motor speed based on button inputs.
    - Added TMC2209 motor configuration parameters in Config.h.
    - Enhanced mutex checks in multiple files to prevent null dereferences.
    - Updated loop logic to include motor control commands for buttons 3, 4, and 5.
    [Config.h, DebugTask.cpp, FFTProcessor.cpp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]
2025-11-29 Add I2C mutex for improved synchronization and stability
    - Created a mutex for I2C operations to prevent concurrent access issues.
    - Updated I2C initialization in MagneticSensor and CurrentSensor to use the mutex.
    - Reduced I2C clock speed in Config.h for stability.
    - Cleaned up debug prints in MotorDriver to reduce clutter.
    [Config.h, CurrentSensor.cpp, MotorDriver.cpp]
2025-11-29 Add automatic Z homing functionality
    - Implemented a homing routine in MotorDriver to facilitate automatic Z homing.
    - Added configuration parameters for homing in Config.h, including current, speed, threshold, direction, and timeout.
    - Updated setup function to initiate the homing process during initialization.
    - Enhanced MotorDriver with detailed logging for the homing process and stall detection.
    [Config.h, MotorDriver.cpp]
2025-11-29 Refactor motor driver settings and enhance homing routine
    - Updated motor driver configuration to disable spreadCycle for silent mode.
    - Adjusted homing routine to include a delay for stabilization and improved logging.
    - Modified speed settings in Config.h for better performance during homing.
    - Cleaned up unnecessary whitespace in setup function.
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2025-11-30 Update motor configuration parameters for optimized performance
    - Reduced REACTION_COOLDOWN_MS for faster response times.
    - Increased TMC_HOMING_CURRENT for improved motor performance during homing.
    - Decreased TMC_HOMING_THRESHOLD to enhance stall detection sensitivity.
    - Adjusted MotorDriver to set speed and acceleration during the homing routine.
    [Config.h, MotorDriver.cpp]
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2025-11-30 Increase motor movement distance for button 3 from 50mm to 150mm to enhance gripping capability.
2025-11-30 Refactor input reading and enhance gripping response
    - Introduced a new input reading function to prioritize sensor data acquisition.
    - Implemented time-sliced reading for current and button inputs to optimize performance.
    - Added a maximum reaction steps limit for grip tightening in response to slip detection.
    - Updated global variables for cycle timing and input reading intervals in ADAPTIVE_GRIPPING_FINAL.ino.
    - Added a new constant for maximum reaction steps in Config.h.
    [Config.h, GrippingFSM.cpp]
2025-11-30 Update slip detection and gripping parameters for improved performance
    - Adjusted SLIP_THRESHOLD and REACTION_COOLDOWN_MS for enhanced responsiveness.
    - Introduced SLIP_DETECTION_IGNORE_CYCLES to filter out mechanical vibrations during movement.
    - Added new_slip_data_ready flag to manage slip detection state more effectively.
    - Updated gripping state machine logic to react only to new slip data.
    - Refined motor speed settings and thresholds in Config.h for optimized gripping behavior.
    [Config.h, GrippingFSM.cpp]
2025-11-30 Enhance debug data handling and serial command processing
    - Updated serial communication speed from 115200 to 921600 for improved data transfer.
    - Added new metrics to DebugData structure for enhanced debugging capabilities, including magnetic field data and current measurements.
    - Implemented command parsing for serial input to toggle various debug data streams, allowing for more flexible monitoring.
    - Refactored debug task to handle both normal and exclusive FFT modes, improving data output efficiency.
    - Introduced a DebugConfig structure to manage streaming options for different debug data types.
2025-11-30 Refactor debug data handling and improve command processing
    - Enhanced serial communication speed to 921600 for better data transfer.
    - Added magnetic field and current metrics to DebugData structure for improved debugging.
    - Implemented command parsing for toggling debug data streams.
    - Refactored debug task to support normal and exclusive FFT modes for efficient data output.
    - Introduced DebugConfig structure for managing streaming options of debug data types.
2025-11-30 Refactor signal analysis GUI and enhance telemetry features
    - Updated data structure to include additional metrics for raw magnetic data and slip detection.
    - Refactored telemetry UI to streamline command and plotting options, improving user experience.
    - Introduced new plot settings for Y-axis scaling and visibility toggling for various data streams.
    - Enhanced data handling in the GUI to accommodate new metrics and improve plotting efficiency.
    - Adjusted file export functionality to include new data fields for comprehensive analysis.
    [Config.h, GrippingFSM.cpp, signal_analysis_gui.py]
2025-11-30 Update baud rate and configuration parameters for improved performance
    - Increased serial communication speed to 2,000,000 for enhanced data transfer efficiency.
    - Adjusted SLIP_THRESHOLD from 60.0f to 80.0f to improve slip detection accuracy.
    - Reduced DEBUG_PRINT_INTERVAL_MS from 120 to 1 for more frequent debug output.
    [Config.h, signal_analysis_gui.py]
2025-12-01 Enhance signal analysis GUI with FFT data handling and improved export functionality
    - Added support for recording and exporting FFT data alongside main signal data.
    - Updated export process to create a dedicated folder for recordings with timestamps.
    - Improved replay functionality to synchronize and load FFT data, ensuring accurate visualization.
    - Enhanced UI elements for better user interaction, including button styling and layout adjustments.
    - Implemented robust error handling during data export and loading processes.
    [signal_analysis_gui.py]
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2025-12-01 Implement checksum verification for serial data in signal analysis GUI
    - Added checksum validation for incoming serial data to ensure data integrity.
    - Enhanced payload handling to support legacy formats without checksums.
    - Improved error handling for JSON parsing based on validated payloads.
    [DebugTask.cpp, signal_analysis_gui.py]
2025-12-01 Add style editor dialog and curve style configuration to signal analysis GUI
    - Introduced a StyleEditorDialog for customizing plot styles, including color, line width, and type.
    - Implemented curve styles configuration for various data streams, enhancing visual representation.
    - Added functionality to toggle FFT Y-scale and update FFT range based on user input.
    - Refactored curve creation logic to utilize a centralized method for improved maintainability.
    - Enhanced UI with buttons for style editing and improved layout for better user interaction.
2025-12-01 Refactor magnetic data handling in signal analysis GUI and debug components
    - Updated variable names for magnetic data to clarify low-pass (`mlx`, `mly`, `mlz`) and high-pass (`mhx`, `mhy`, `mhz`) filtering.
    - Enhanced telemetry toggles in the GUI to support new naming conventions for magnetic data streams.
    - Improved error handling in the serial worker to ensure proper emission of error signals when running.
    - Added legacy support for previous magnetic data keys to maintain compatibility with existing data formats.
    - Updated documentation to reflect changes in telemetry commands for low-pass and high-pass filtered data.
    [DebugTask.cpp, signal_analysis_gui.py]
2025-12-01 Refactor serial data handling in signal analysis GUI for batch processing
    - Updated SerialWorker to emit lists of data and raw strings for improved efficiency.
    - Implemented batch processing of incoming serial data to reduce UI lag and enhance performance.
    - Adjusted connection handling in the GUI to link to new batch data handlers.
    - Enhanced error handling and reduced unnecessary delays in serial communication.
    - Increased buffer size in Arduino setup to prevent blocking and latency issues.
    [Config.h, DebugTask.cpp, signal_analysis_gui.py]
2025-12-01 Enhance signal analysis GUI with dual plot settings and improved data handling
    - Introduced a new PlotSettingsWidget for managing individual plot settings, including auto-scaling and DC centering for two time series plots.
    - Updated serial data handling to optimize batch processing and reduce UI lag.
    - Enhanced layout and visibility toggles for FFT and time series plots, allowing users to switch between views seamlessly.
    - Refactored curve creation logic to support multiple plots, improving maintainability and user experience.
    - Adjusted sidebar layout for better organization and accessibility of controls.
2025-12-01 Enhance checksum handling in SerialWorker for improved data integrity
    - Added whitespace stripping for checksum values to ensure accurate validation.
    - Implemented strict mode to reject lines without checksums, preventing data corruption.
    - Updated comments for clarity on checksum verification process.
    [signal_analysis_gui.py]
2025-12-01 Update SerialWorker to improve flow control handling
    - Set dsrdtr=False in serial.Serial to enhance flow control and prevent ESP32 reset issues on certain boards.
    - Removed explicit DTR/RTS settings to streamline serial communication.
    [signal_analysis_gui.py]
2025-12-01 Enhance signal analysis GUI with new plot settings and improved data handling
    - Added a spin box for configuring the X-axis window size, allowing users to adjust the number of samples displayed.
    - Increased buffer size to support larger data windows, improving data handling capabilities.
    - Implemented lazy truncation for data storage to optimize performance and reduce overhead during data recording.
    - Updated plot rendering to respect the new window size setting for better visualization of data.
    - Added a style setting to enforce the Fusion theme for improved UI consistency.
2025-12-01 Update gripping logic and configuration parameters for improved slip detection
    - Added a new constant for grip slip margin to reduce false positives during slip detection.
    - Removed unnecessary slip detection ignore logic during movement to streamline the gripping state machine.
    - Adjusted slip reaction logic to utilize the new grip slip margin, enhancing responsiveness to slip events.
    [Config.h, GrippingFSM.cpp]
2025-12-01 Add raw data recording and reception timestamp handling in signal analysis GUI
    - Introduced functionality to record raw JSON packets immediately when recording is active, enhancing data preservation.
    - Added a new 'recv_ts' key to store reception timestamps alongside existing data.
    - Updated the toggle recording method to create a directory for saving recordings and handle file operations more robustly.
    - Enhanced data processing to ensure both raw and filtered data are managed effectively during recording and replay.
    - Improved replay file loading to support both raw JSON and legacy CSV formats, ensuring compatibility with existing data workflows.
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2025-12-03 Initialize raw sensor variables in readInputsSequentially function to prevent uninitialized usage
2025-12-03 Update slip detection threshold and modify FFT processing return value
    - Changed SLIP_THRESHOLD from an incorrect initialization to a defined value of 40.0f for accurate slip detection.
    - Updated the FFT processing function to return a boolean indicating if the FFT process has just completed, enhancing the clarity of the processing state.
    [Config.h, FFTProcessor.cpp]
2025-12-03 Enhance signal analysis GUI with color bar toggle and improved spectrogram layout
    - Added a checkbox to toggle the visibility of the color bar in the spectrogram view, enhancing user control over the display.
    - Refactored the spectrogram plot into a dedicated GraphicsLayoutWidget for better organization and layout management.
    - Updated the spectrogram's Y-axis ticks for improved clarity, ensuring a more informative visualization of frequency data.
    - Enhanced the handling of the histogram legend to avoid confusion with frequency distribution, focusing on color representation.
    [signal_analysis_gui.py]
2025-12-03 Update slip detection parameters for improved accuracy
    - Adjusted SLIP_THRESHOLD from 40.0f to 24.0f to enhance slip detection sensitivity.
    - Modified SLIP_FREQ_START_HZ from 80 to 40 and SLIP_FREQ_END_HZ from 200 to 125 to refine frequency detection range.
    - Increased GRIP_MAGNITUDE_THRESHOLD from 1.2f to 2.0f to better differentiate grip strength.
    [Config.h]
2025-12-04 Update slip detection parameters and logic for improved grip response
    - Increased SLIP_THRESHOLD from 24.0f to 30.0f to enhance slip detection sensitivity.
    - Modified SLIP_FREQ_START_HZ from 40 to 60 to refine frequency detection range.
    - Decreased GRIP_SLIP_MARGIN_FALSE_POSITIVE from 6.0f to 2.5f to improve grip response accuracy.
    - Added a condition in the gripping logic to reset slip indication based on the new margin, enhancing grip adjustment behavior.
    [Config.h, GrippingFSM.cpp]
2025-12-12 Remove obsolete files and dependencies from the project
    - Deleted requirements.txt, signal_analysis_gui.py, and various source files related to the adaptive gripping functionality.
    - Cleaned up the project structure by removing unused drivers, logic modules, and configuration files.
    - Eliminated raw data recordings to streamline the repository and focus on essential components.
    [gripper.step]
2025-12-12 Update README and requirements for adaptive gripper project
    - Revised README.md to reflect project scope, features, and detailed documentation structure for the adaptive gripper with micro-vibration based slip detection.
    - Added sections on system architecture, hardware specifications, firmware details, and desktop application features.
    - Updated requirements.txt to include PyMuPDF for enhanced document handling capabilities in the software.
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2025-12-12 Update README to reflect new documentation path and project structure
    - Changed the full protocol documentation link in README.md to point to the updated `firmware/Thesis_Gripper/debugCommands.md`.
    - Renamed the project directory in the README to `Adaptive-Gripper-with-Micro-Vibration-Based-Slip-Detection` for consistency with the new structure.
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2025-12-12 Update README with new images and enhanced test platform description
    - Replaced outdated CAD model image with the latest version.
    - Added images of the test platform overview and physical assembly for better visualization.
    - Expanded the description of the test platform's purpose to emphasize its role in eliminating human variability during experiments.
2025-12-23 Fixed large file with LFS
    [coushon_compliant_v3_0.4mm nozzle.obj, gripper.3mf]
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2025-12-28 Update README.md to replace images for improved clarity and relevance
    - Updated images to better represent the project components, including the lifter render and sensor element.
    - Enhanced visual presentation by adjusting image sizes for improved visibility.
